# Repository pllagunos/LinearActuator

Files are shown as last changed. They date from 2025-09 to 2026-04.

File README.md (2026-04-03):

# 3D-Printed NEMA 17 Linear Actuator

A 3D-printed linear actuator project using a NEMA 17 stepper motor and a custom Arduino-based controller. This project was originally designed to automatically open and close the main chimney flue on a large industrial kiln. It is inspired by the robust and precise mechanics of 3D printers.

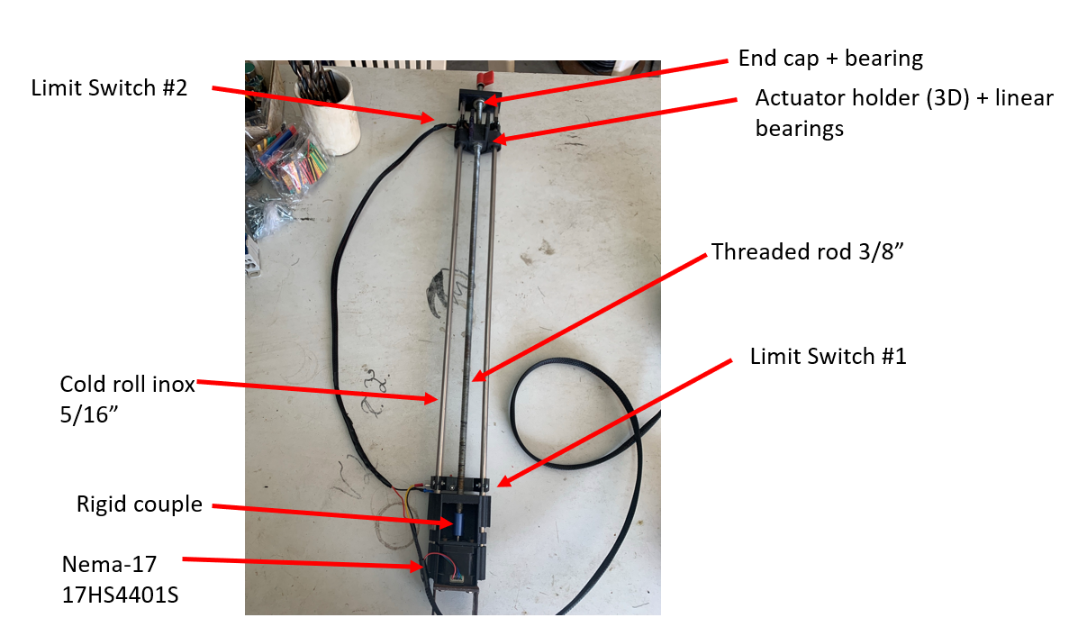
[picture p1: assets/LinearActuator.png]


## Features
* **Precise Control:** Uses a NEMA 17 stepper motor and A4988 driver for accurate positioning.
* **Custom PCB:** Includes a custom-designed PCB for a clean and reliable control circuit.
* **Robust Materials:** Designed with parts printed in Carbon Fiber PETG for strength and PLA for enclosures.
* **End-Stops:** Incorporates limit switches for homing and safe operation.
* **Expandable:** The controller includes a header for an ESP32, allowing for future Wi-Fi or IoT integration.

## Bill of Materials (BOM)

### Electronics
| Part | Quantity | Notes |
| --- | :---: | --- |
| NEMA 17 Stepper Motor | 1 | Model: 17HS4401S |
| Arduino Pro Mini | 1 |3.3V version |
| A4988 Stepper Driver  | 1 | Remember to set Vref! (See instructions) |
| Limit Switches | 2 | For open/closed end-stops  |
| Push Buttons | 2 | Normally Open (for manual control) |
| Custom Controller PCB | 1 | Gerber/EasyEDA files are in `/hardware`  |
| *See PCB BOM for all board components* | - | Resistors, capacitors, headers, etc. |

### Mechanical
| Part | Quantity | Notes |
| --- | :---: | --- |
| 3/8" Threaded Rod | 1 | The main lead screw |
| 5/16" Stainless Steel Rods | 2 | Smooth guide rods |
| Rigid Coupler | 1 | Connects motor to threaded rod  |
| Linear Bearings | 2+ | To slide on the smooth rods |
| *Various Screws, Nuts, and Fasteners* | - | See the SolidWorks assembly file |

### 3D Printed Parts
| Part | Material | Notes |
| --- | :---: | --- |
| Actuator Body/Mounts  | Carbon Fiber | Files are in `/hardware/Mechanical/stl printing/` |
| Controller Enclosure  | PLA | |

## Wiring & Assembly

### Mechanical
The mechanical structure can be assembled by following the SolidWorks design files located in the `/hardware/Mechanical/solidworks/` directory. The main assembly file is `Ensamblaje2_v3.SLDASM`.

### Controller and Wiring
The electronics are centered around a custom PCB. Please refer to the schematic for detailed connections between the Arduino, A4988 driver, motor, limit switches, and buttons.

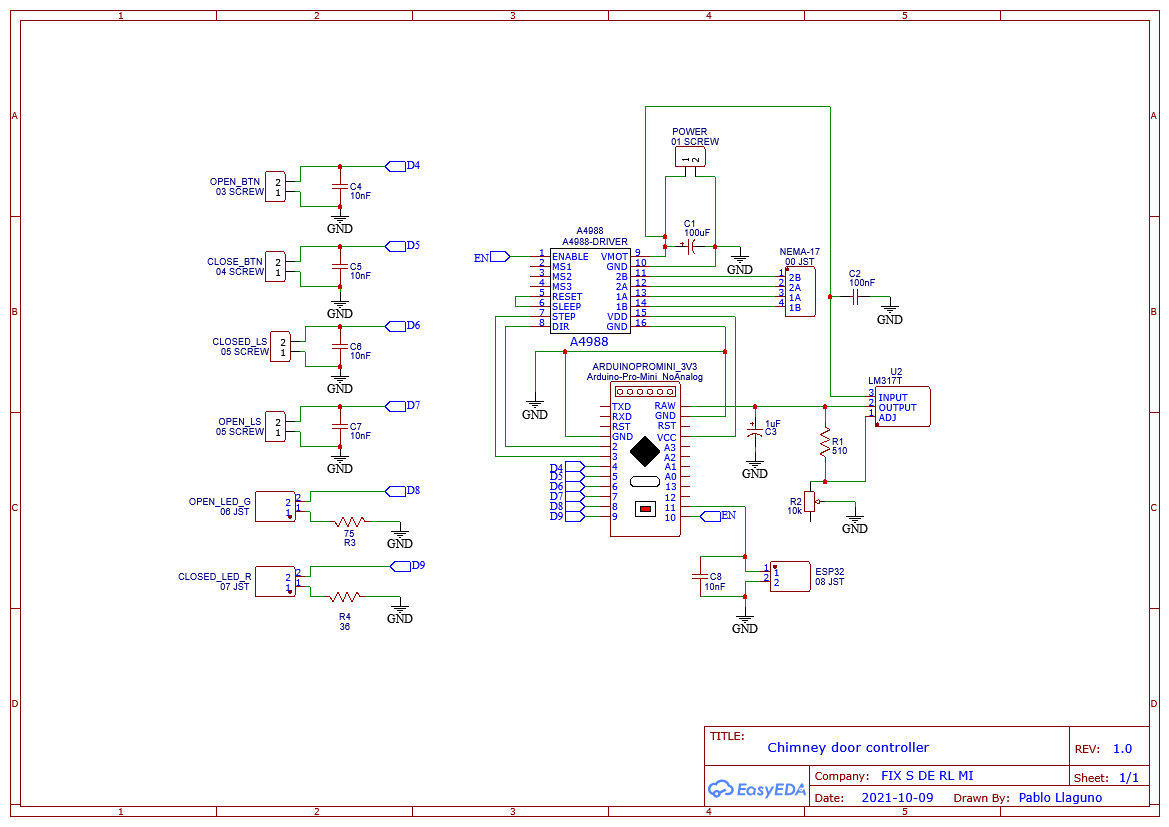
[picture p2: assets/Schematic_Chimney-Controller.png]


**Important:** It is highly recommended to use shielded cables (e.g., FTP) for all connections to the controller to prevent electromagnetic interference, especially near mains power lines.

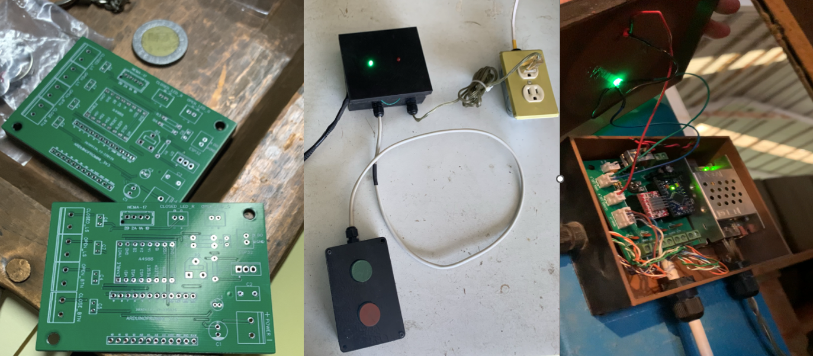
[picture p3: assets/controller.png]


## A4988 Driver Setup (Crucial Step!)
Before operating the motor, you **must** set the maximum current limit on the A4988 driver to protect the motor. This is done by adjusting the reference voltage (`Vref`) on the small potentiometer on the driver board.

1.  **Calculate `Vref`**: The formula is `Vref = I_max * 8 * R_sense`.
    * The NEMA 17 17HS4401S motor has a max current (`I_max`) of 1.7A.
    * The sense resistors (`R_sense`) on the A4988 are typically 0.1Ω.
    * For safety, we will target a lower current of **1.0A**.
    * Therefore, `Vref = 1.0 * 8 * 0.1 = 0.8V`.

2.  **Adjust the Potentiometer**:
    * Connect the controller board to your power supply but **do not connect the motor**.
    * Set your multimeter to DC voltage mode.
    * Place the negative probe on a GND pin.
    * Place the positive probe on the metal top of the potentiometer.
    * Carefully turn the potentiometer until the multimeter reads your target `Vref` (e.g., 0.8V).

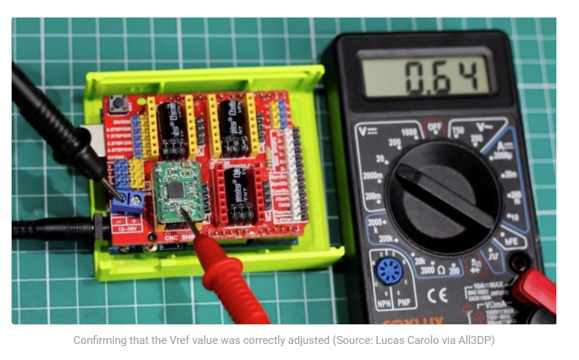
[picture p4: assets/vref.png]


## Code
The Arduino code is located in the `Chimenea_Botones_v2.ino` file. It uses the `AccelStepper` library for motor control.

The main `loop()` function continuously checks for input from the push buttons or an external signal (originally from an ESP32) and calls the appropriate functions to move the motor.

It is a very simple program but serves as a minimal example on how to use the actuator.

## Acknowledgements
A special thank you to my friends **[Ricardo Rosas](https://github.com/RicardoRosasE) and [Gilberto Juarez](https://github.com/GJRangel)**, who were instrumental in the build - specially the mechanical design. This project would not have been possible without their help.

## ✅ To-Do List
- [x] Create initial detailed README
- [x] Upload Gerber files and a detailed BOM for the PCB
- [x] Add hardware license
- [ ] Convert necessary solidwork parts to STL files

## License
This project uses a dual-license model:
* **Software:** All source code is licensed under the **MIT License**. See the `LICENSE` file for details.
* **Hardware:** All hardware design files (schematics, PCB, CAD models, and STL files) are licensed under the **Creative Commons Attribution-ShareAlike 4.0 International License (CC BY-SA 4.0)**. See the `LICENSE-HARDWARE.md` file for details.

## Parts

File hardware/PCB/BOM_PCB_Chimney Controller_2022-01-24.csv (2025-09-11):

ID | Name | Designator | Footprint | Quantity | Manufacturer Part | Manufacturer | Supplier | Supplier Part | Price
1 | 10nF | C4,C5,C6,C7,C8 | CAP-TH_L5.0-W2.5-P2.54-D0.7 | 5 | CT1-F5Y5V2A103MSPW | Guangdong Fenghua Advanced Tech | LCSC | C277962 | $0.012
2 | Arduino-Pro-Mini_NoAnalog | ARDUINOPROMINI_3V3 | ARDUINO-PRO-MINI-NOANALOG | 1 |  |  | MC |  | $4.990
3 | 05 SCREW | CLOSED_LS,OPEN_LS | CONN-TH_2P-P5.00 | 2 |  |  | Steren |  | $0.100
4 | 04 SCREW | CLOSE_BTN | CONN-TH_2P-P5.00 | 1 |  |  | Steren |  | $0.250
5 | 03 SCREW | OPEN_BTN | CONN-TH_2P-P5.00 | 1 |  |  | Steren |  | $0.250
6 | A4988-DRIVER | A4988 | A4988-DRIVER | 1 | A4988 |  | MC |  | $2.100
7 | 100nF | C2 | RAD-0.2 | 1 | 0.1UF(104) +-20% 63v | LCSC | LCSC | C19355 | $0.011
8 | 1uF | C3 | CAP-TH_BD4.0-P1.50-D0.8-FD | 1 | 1uF 50V 4*5 | ValuePro | LCSC | C47848 | $0.013
9 | LM317T | U2 | TO-220AB-3_L10.4-W4.6-P2.54-T | 1 | LM317T | STMicroelectronics | LCSC | C361026 | $0.897
10 | 10k | R2 | RES-ADJ-SMD_RM065-V1 | 1 | Blue and white adjustable resistance RM065-V1-102 | ReliaPro | LCSC | C53566 | $0.034
11 | 510 | R1 | R_AXIAL-0.3 | 1 |  |  | Steren |  | $0.040
12 | 01 SCREW | POWER | CONN-TH_2P-P5.00 | 1 |  |  | Steren |  | $0.250
13 | 100uF | C1 | CAP-TH_BD1.0-P2.54-D6.3-FD | 1 | 100uF 35V 6.3*11 | ValuePro | LCSC | C45076 | $0.013
14 | 08 JST | ESP32 | CONN-TH_B2B-XH-2-LF-SN | 1 | - | JST Sales America | LCSC | C158014 | $0.084
15 | 00 JST | NEMA-17 | CONN-TH_B4B-XH-AM-LF-SN | 1 | B4B-XH-AM(LF)(SN) | JST Sales America | LCSC | C161871 | $0.095
16 | 75 | R3 | R_AXIAL-0.3 | 1 |  |  | Steren |  | $0.040
17 | 36 | R4 | R_AXIAL-0.3 | 1 |  |  | Steren |  | $0.040
18 | 07 JST | CLOSED_LED_R | CONN-TH_B2B-XH-2-LF-SN | 1 | - | JST Sales America | LCSC | C158014 | $0.084
19 | 06 JST | OPEN_LED_G | CONN-TH_B2B-XH-2-LF-SN | 1 | - | JST Sales America | LCSC | C158014 | $0.084
 |  |  |  |  |  |  |  | Total | $9.54 | USD
 |  |  |  |  |  |  |  |  | $190.70 | MXN

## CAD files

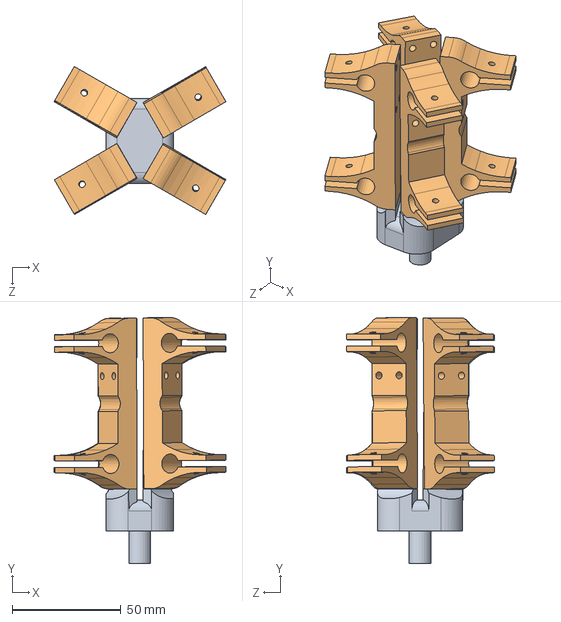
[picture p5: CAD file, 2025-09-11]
hardware/Mechanical/solidworks/FlaskOfSoporteLimit.SLDASM
78.9 x 112.9 x 67.9 mm
Soporte_limit_v3 x 4
Feeder

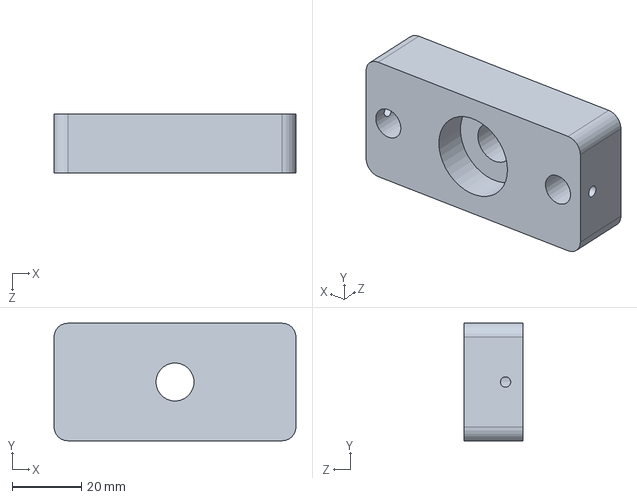
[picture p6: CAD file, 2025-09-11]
hardware/Mechanical/solidworks/CH_End_001_v3.SLDPRT
70.0 x 34.0 x 17.0 mm

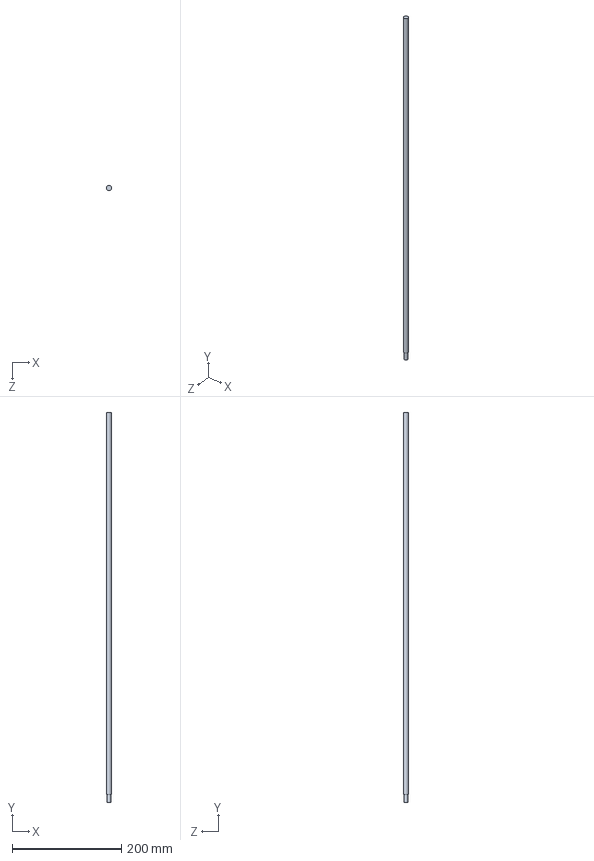
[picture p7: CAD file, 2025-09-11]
hardware/Mechanical/solidworks/CH_Esparrago_001_v3.SLDPRT
9.53 x 715.0 x 9.53 mm

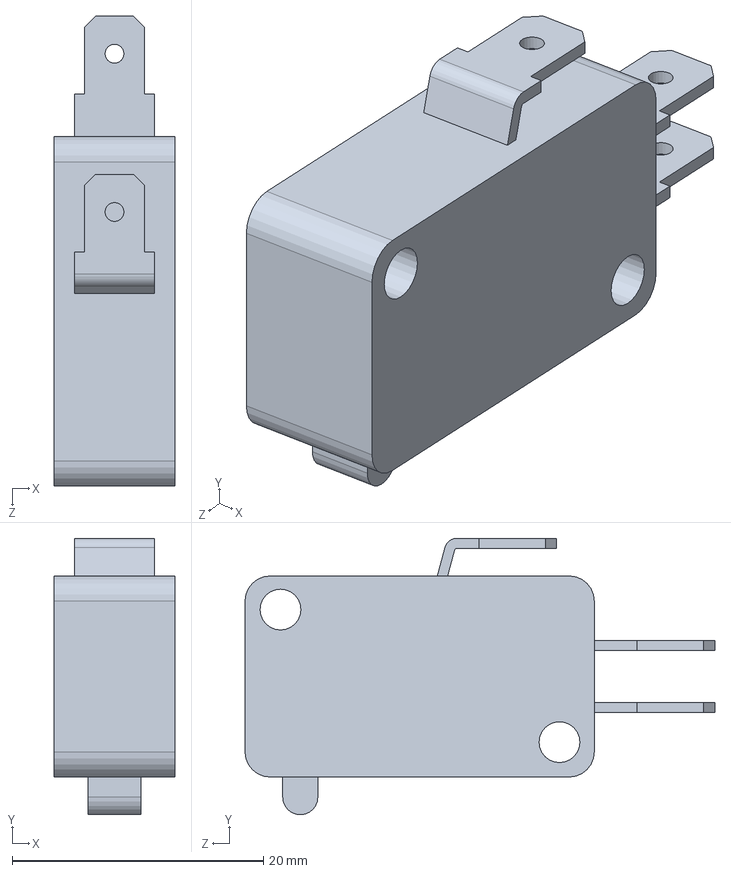
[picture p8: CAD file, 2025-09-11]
hardware/Mechanical/solidworks/Limit Switch 2_v3.SLDPRT
9.60 x 22.0 x 37.4 mm

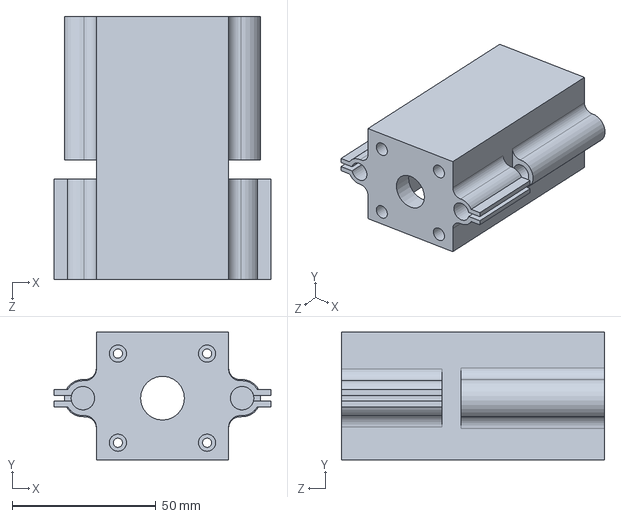
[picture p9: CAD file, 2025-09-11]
hardware/Mechanical/solidworks/CH_Refuerzo_002_v3.SLDPRT
75.4 x 44.5 x 91.5 mm

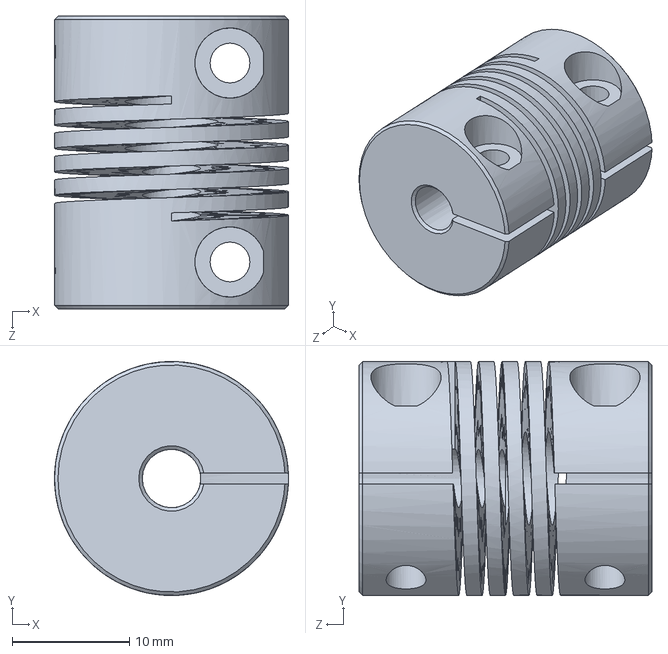
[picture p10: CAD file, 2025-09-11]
hardware/Mechanical/solidworks/Flexible Coupling 5mm x 8mm_v3.SLDPRT
20.0 x 20.0 x 25.0 mm

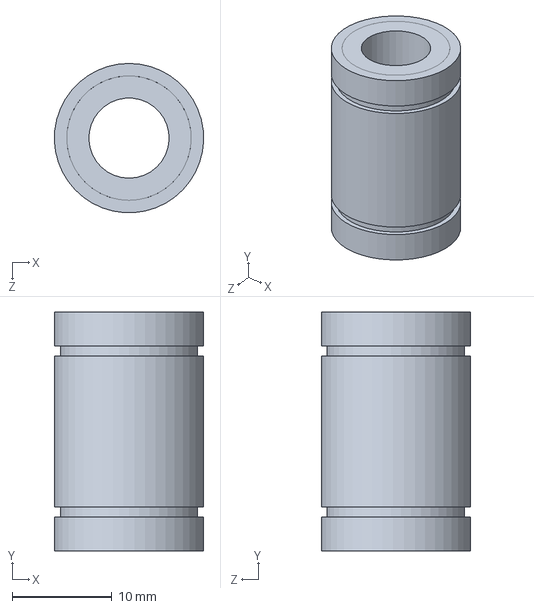
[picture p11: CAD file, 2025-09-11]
hardware/Mechanical/solidworks/LM8UU_Baleros_Lineles_v3.SLDPRT
15.0 x 24.0 x 15.0 mm

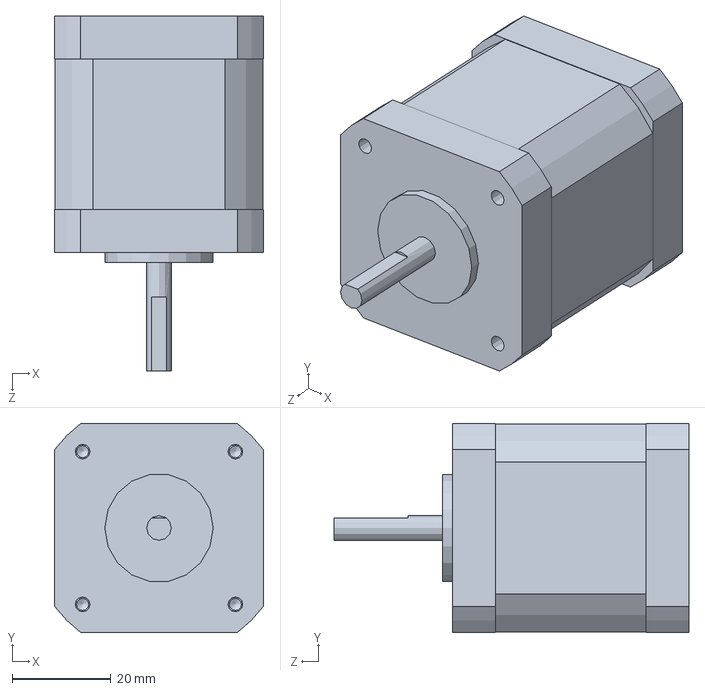
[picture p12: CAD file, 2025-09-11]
hardware/Mechanical/solidworks/Nema 17 Stepper Motor_v3.SLDPRT
42.4 x 42.4 x 72.0 mm

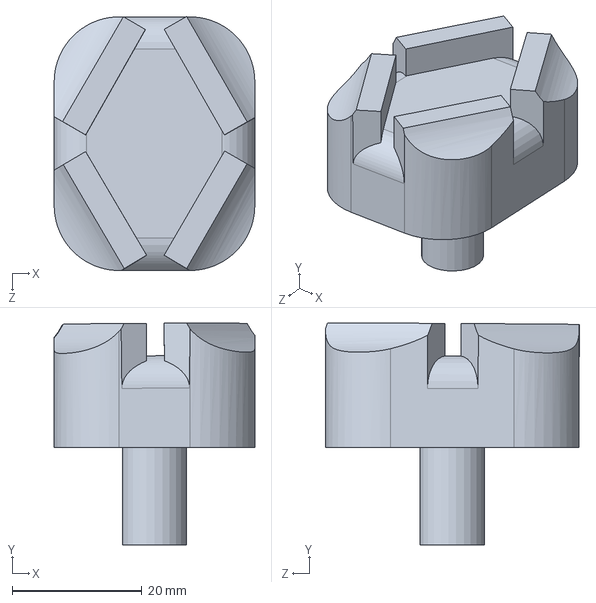
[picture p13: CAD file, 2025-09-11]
hardware/Mechanical/solidworks/Feeder.SLDPRT
30.9 x 34.2 x 39.2 mm

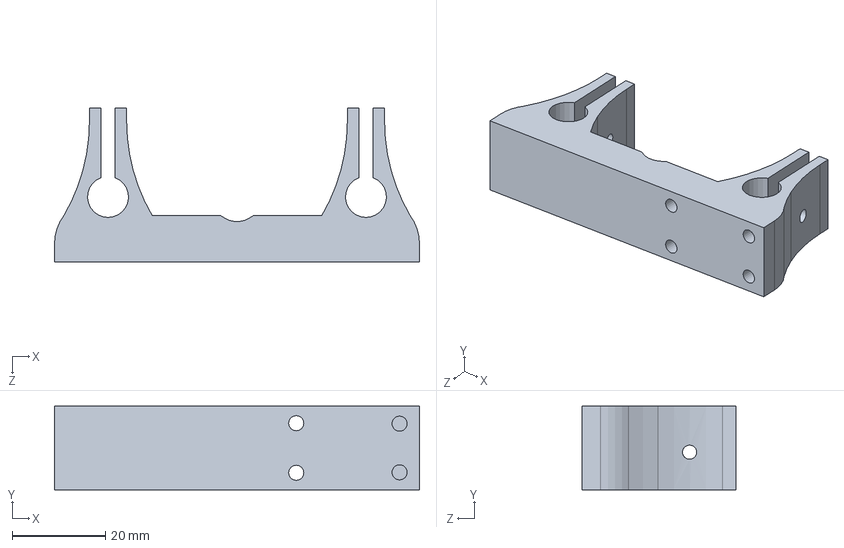
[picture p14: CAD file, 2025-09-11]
hardware/Mechanical/solidworks/Soporte_limit_v3.SLDPRT
78.4 x 18.0 x 33.1 mm

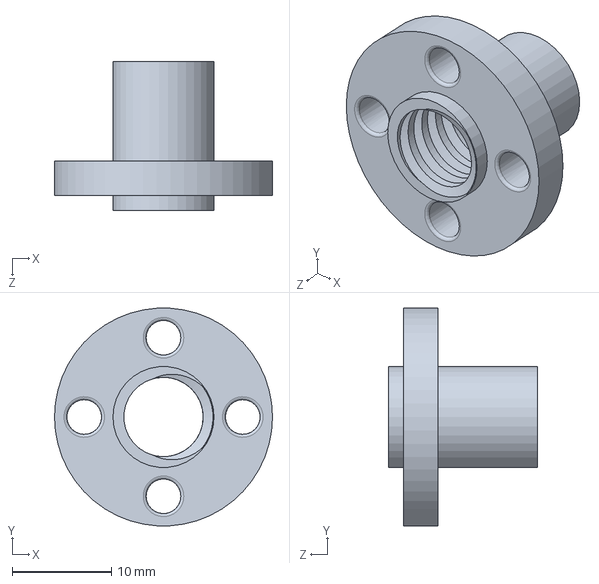
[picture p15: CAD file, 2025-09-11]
hardware/Mechanical/solidworks/LeadScrew Nut 8mm x 2mmPitch.SLDPRT
22.0 x 22.0 x 15.0 mm

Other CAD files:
hardware/Mechanical/2D working mechanism.SLDPRT
hardware/Mechanical/solidworks/CH_Tensor de guia_001_v3.SLDPRT
hardware/Mechanical/solidworks/CH_Bandera_001_v3.SLDPRT
hardware/Mechanical/solidworks/CH_Guia lineal 5_16_001_v3.SLDPRT
hardware/Mechanical/stl printing/CH_End_001_v3.STL
hardware/Mechanical/stl printing/Feeder.STL
hardware/Mechanical/stl printing/Soporte_limit_v3.STL

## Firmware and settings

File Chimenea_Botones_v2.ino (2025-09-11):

// Define pin connections
#define dirPin 2
#define stepPin 3
#define openButton 4
#define closeButton 5
#define closedLimitSwitch 6 // top limit switch corresponds to closed door
#define openLimitSwitch 7   // bottom limit switch corresponds to open door
#define IsOpenLED 8
#define IsClosedLED 9
#define enable 10
#define ESPsignal 11

boolean openPressed = false;
boolean closePressed = false;
boolean IsOpen = false;
boolean IsClosed = false;

void setup() {
  pinMode(dirPin, OUTPUT);
  pinMode(stepPin, OUTPUT);
  pinMode(IsOpenLED, OUTPUT);
  pinMode(IsClosedLED, OUTPUT);

  pinMode(openButton, INPUT_PULLUP);        // open chimney door
  pinMode(closeButton, INPUT_PULLUP);       // close chimney door
  pinMode(closedLimitSwitch, INPUT_PULLUP); // goes to limit switch at the top
  pinMode(openLimitSwitch, INPUT_PULLUP);   // goes to limit switch at bottom
  pinMode(ESPsignal, INPUT_PULLUP);         // ESP trigger signal to close chimney
}

void loop() {
  digitalWrite(enable, HIGH); // stepper is OFF, only ON if it has to move
  readButtons();
  readESPsignal();
  actOnButtons();
}

void readButtons() {
  closePressed = false; openPressed = false;
  if (digitalRead(openButton) == LOW) {
    openPressed = true;
    btnBounce(openButton);
  }
  if (digitalRead(closeButton) == LOW) {
    closePressed = true;
    btnBounce(closeButton);
  }
}

void btnBounce(int btnPin) {
  while (digitalRead(btnPin) == LOW);
  delay(20);
}

void actOnButtons() {
  readStates();
  if (openPressed == true) { 
    //OPEN();
    digitalWrite(enable, LOW);
    digitalWrite(dirPin, HIGH);
    
    while (IsOpen == false) {
      STEP();
      if( closePressed == true || openPressed == true) {return;}      
    }
  }
  
  if (closePressed == true) {
    //CLOSE();
    digitalWrite(enable, LOW);
    digitalWrite(dirPin, LOW);
    
    while (IsClosed == false) {
      STEP();
      if( closePressed == true || openPressed == true) {return;}
    }       
  }
  
}

void STEP() {
  // Spin the stepper motor
  digitalWrite(stepPin, HIGH);
  delayMicroseconds(700);
  digitalWrite(stepPin, LOW);
  delayMicroseconds(700);
  readStates();
  readButtons();
}

void readStates() {
  IsOpen = false;
  IsClosed = false;
  digitalWrite(IsOpenLED, LOW);
  digitalWrite(IsClosedLED, LOW); 
   
  if (digitalRead(openLimitSwitch) == LOW) {
    IsOpen = true;
    digitalWrite(IsOpenLED, HIGH);
    digitalWrite(IsClosedLED, LOW);
  }
  if (digitalRead(closedLimitSwitch) == LOW) {
    IsClosed = true;
    digitalWrite(IsClosedLED, HIGH);
    digitalWrite(IsOpenLED, LOW);
  }
}

void readESPsignal() {
  if (digitalRead(ESPsignal) == LOW) {
    delay(100);
    if (digitalRead(ESPsignal) == HIGH) {
      delay(50);
      if (digitalRead(ESPsignal) == LOW) {
        delay(50);
        if (digitalRead(ESPsignal) == HIGH) openPressed = true;
      }
    }
  }
  //while (digitalRead(ESPsignal) == LOW); // hold while it's LOW
  //delay(20); // avoid EMI bounce?
}

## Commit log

2025-09-11 Added Arduino file and gitignore file
2025-09-11 Added hardware files. All solidwork parts + explanation of mechanism + assembly. Not all STL models have been added. Added BOM for PCB, must add.
    [2D working mechanism.SLDPRT, BOM_PCB_Chimney Controller_2022-01-24.csv, CH_Bandera_001_v3.SLDPRT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]
2025-09-17 Modified README. Added gerber, schematics nd pictures
